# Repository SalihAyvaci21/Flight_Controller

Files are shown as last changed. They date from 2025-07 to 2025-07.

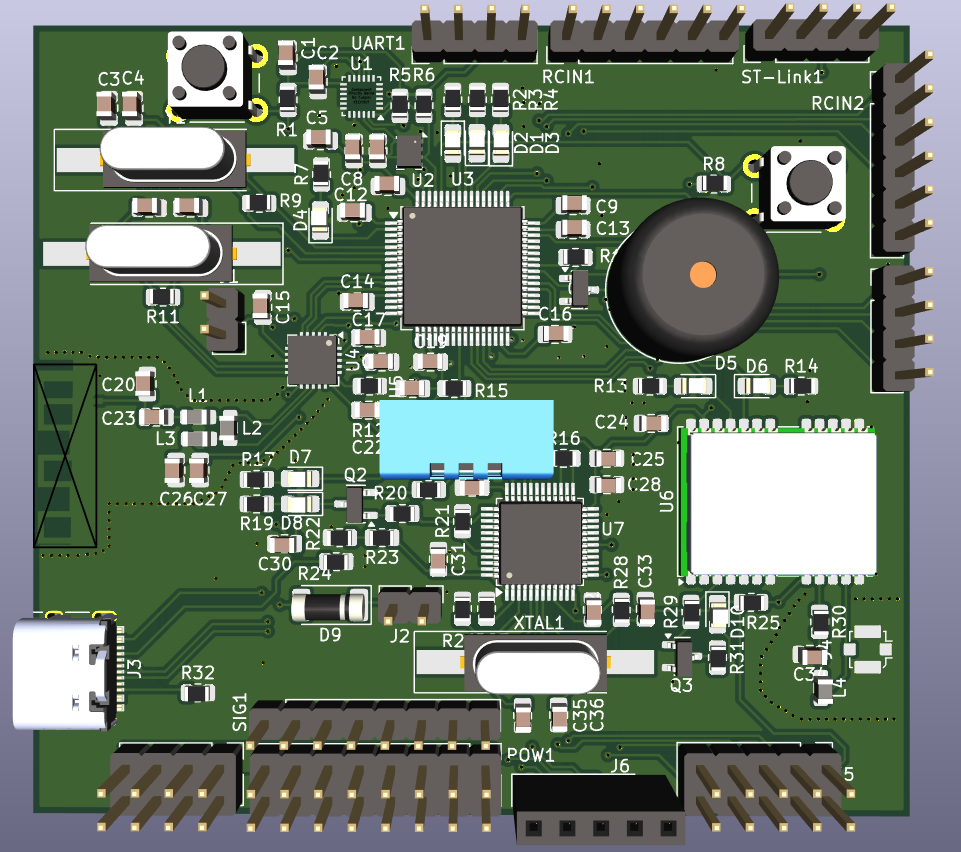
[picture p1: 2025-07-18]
Ucus kartı v312/Ucus kartı v3/Images/3D Images.PNG

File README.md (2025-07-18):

#  STM32F405RGT Flight Controller & Development Board

Bu proje, **STM32F405RGT6 (64-pin)** mikrodenetleyicisi tabanlı bir uçuş kartı ve aynı zamanda **entegre ST-LINK** programlayıcısı ile bir geliştirme kartı olarak kullanılabilecek bir donanım platformudur.  

Kart, uçuş modlarını kontrol etmek için kritik sensörler ve genişletilebilir pin yapısıyla tasarlanmıştır. Hem uçuş kontrolü hem de genel gömülü sistem geliştirme için idealdir.

## ✨ Özellikler

- **MCU**: STM32F405RGT6 (Cortex-M4, 1MB Flash, 192KB SRAM, 64-pin LQFP)
- **ST-LINK v2.1**: Dahili programlayıcı (STM32F103CBT tabanlı)
- **Sensörler**:
  - MPU-9250 (9 Eksen IMU - Gyro, Accelerometer, Magnetometer)
  - BMP180 (Barometrik basınç ve sıcaklık sensörü)
  - DHT11 (Nem ve sıcaklık sensörü)
  - (MPU9250 + BMP180 kombinasyonu Türkiye’de kolay bulunabilir)
- **Kablosuz Haberleşme**:
  - **nRF24L01**: Yer istasyonu ile veri alışverişi
  - **GPS**: Neo-8Q (Pin-to-Pin uyumlu M8N alternatifi)
  - Harici anten çıkışı (değiştirilebilir)
- **GPIO**:
  - 4x LED (Uçuş modları için): `PA0`, `PA1`, `PA2`, `PA3`
  - 2x Güç LED’i (3.3V & 5V)
  - Buzzer: `PA8`
  - PWM Çıkışları: `PA0` - `PA3`
  - Boot & Reset düğmeleri
  - Programlama pinleri: `PA13`, `PA14` (SWD)
  - UART4 (ST-LINK üzerinden): `PC10` (TX), `PC11` (RX)
  - Çoğu GPIO **boşta bırakıldı**, kullanıcı entegrasyonu için hazır

---

## 📡 Kablosuz Özellikler

| Bileşen | Açıklama |
|---|---|
| **nRF24L01** | Yer istasyonu ile haberleşme için |
| **Neo-8Q GPS** | Konumlandırma ve uçuş rotası takibi |
| **Anten Çıkışı**| Harici anten bağlantısı, değiştirilebilir |

---

## 🛠️ Kullanım Senaryoları

- 🚁 Drone/UAV uçuş kontrolü
- 🧑‍💻 STM32 geliştirme platformu
- 📡 Kablosuz veri iletimi prototipleri
- 📦 Sensör entegrasyonu için araştırma & eğitim projeleri

---

## 🔌 Pinout & Peripherals

| Fonksiyon | Pinler |
|---|---|
| Uçuş Modu LED’leri | PA0, PA1, PA2, PA3  |
| Güç LED’leri | 3.3V, 5V |
| Buzzer | PA8 |
| Boot & Reset Butonları| GPIO kontrollü |
| PWM Çıkışları | PA0 - PA3 |
| SWD Programlama | PA13, PA14 |
| UART4 (ST-LINK) | PC10 (TX), PC11 (RX)|
| GPS | Harici bağlantı |
| nRF24L01 | SPI bağlantısı |

---

## ⚙️ Programlama & Debug

- **ST-LINK Dahili**
  - STM32F103CBT tabanlı entegre ST-LINK
  - SWD pinleri dışarı alınmıştır (`PA13`, `PA14`)
  - STM32CubeProgrammer veya OpenOCD ile uyumlu
- **UART Debugging**
  - UART4 üzerinden ST-LINK’e bağlantı

---

## 📦 Entegrasyon & Genişletilebilirlik

- Tüm kritik uçuş sensörleri **entegre edilmiştir**  
- Çoğu GPIO boşta bırakılmıştır – ek donanımlar ve özel modüller için kullanılabilir
- Geliştiriciler kendi devrelerini veya sensörlerini kolayca entegre edebilir

---

## 🚀 Başlarken

1. USB üzerinden bilgisayara bağlanın (ST-LINK otomatik tanınır)
2. STM32CubeProgrammer ile firmware yükleyin
3. Harici sensörleri ve modülleri GPIO’lara bağlayın
4. UART4 ile seri haberleşmeyi başlatın

---

## 📃 Lisans

Bu proje tamamen açık kaynaklıdır. İsteyen herkes geliştirme ve entegrasyon yapabilir.

---

## 📝 Notlar
- MPU9250 ve BMP180 Türkiye’de kolay bulunabilir ve birlikte modül olarak satılmaktadır.
- GPS için Neo-8Q kullanılmıştır; Pin-to-Pin uyumlu M8N de kullanılabilir.

---

STM32F405RGT Flight Controller & Development Board
This project is a hardware platform based on the STM32F405RGT6 (64-pin) microcontroller, designed as both a flight controller and a development board with an integrated ST-LINK programmer.

The board is equipped with critical sensors for flight modes and an extendable pin structure, making it ideal for both flight control and general embedded system development.

✨ Features
MCU: STM32F405RGT6 (Cortex-M4, 1MB Flash, 192KB SRAM, 64-pin LQFP)

ST-LINK v2.1: Built-in programmer (based on STM32F103CBT)

Sensors:

MPU-9250 (9-axis IMU - Gyroscope, Accelerometer, Magnetometer)

BMP180 (Barometric pressure and temperature sensor)

DHT11 (Humidity and temperature sensor)

(MPU9250 + BMP180 combo is widely available)

Wireless Communication:

nRF24L01: For data exchange with ground station

GPS: Neo-8Q (Pin-compatible with M8N alternative)

External antenna connector (replaceable)

GPIO:

4x LEDs (for flight modes): PA0, PA1, PA2, PA3

2x Power LEDs (3.3V & 5V)

Buzzer: PA8

PWM Outputs: PA0 - PA3

Boot & Reset buttons

Programming pins: PA13, PA14 (SWD)

UART4 (via ST-LINK): PC10 (TX), PC11 (RX)

Most GPIOs are left free for user integration

📡 Wireless Features
Component	Description
nRF24L01	Communication with ground station
Neo-8Q GPS	Positioning and flight route tracking
Antenna Out	External antenna connector, replaceable

🛠️ Use Cases
🚁 Drone/UAV flight control

🧑‍💻 STM32 development platform

📡 Wireless data transmission prototypes

📦 Research & educational projects for sensor integration

🔌 Pinout & Peripherals
Function	Pins
Flight Mode LEDs	PA0, PA1, PA2, PA3
Power LEDs	3.3V, 5V
Buzzer	PA8
Boot & Reset Buttons	GPIO controlled
PWM Outputs	PA0 - PA3
SWD Programming	PA13, PA14
UART4 (ST-LINK)	PC10 (TX), PC11 (RX)
GPS	External connection
nRF24L01	SPI interface

⚙️ Programming & Debug
Built-in ST-LINK

Based on STM32F103CBT

SWD pins exposed (PA13, PA14)

Compatible with STM32CubeProgrammer and OpenOCD

UART Debugging

Connected via UART4 to ST-LINK

📦 Integration & Expandability
All critical flight sensors are integrated

Most GPIOs are left free – ready for additional hardware or custom modules

Developers can easily integrate their own circuits or sensors

🚀 Getting Started
Connect to PC via USB (ST-LINK auto-detected)

Flash firmware using STM32CubeProgrammer

Connect external sensors and modules to GPIOs

Start serial communication via UART4

📃 License
This project is fully open-source. Anyone is free to develop and integrate.

📝 Notes
MPU9250 and BMP180 are widely available and often sold as combined modules.

Neo-8Q GPS is used; Pin-compatible M8N can also be used.

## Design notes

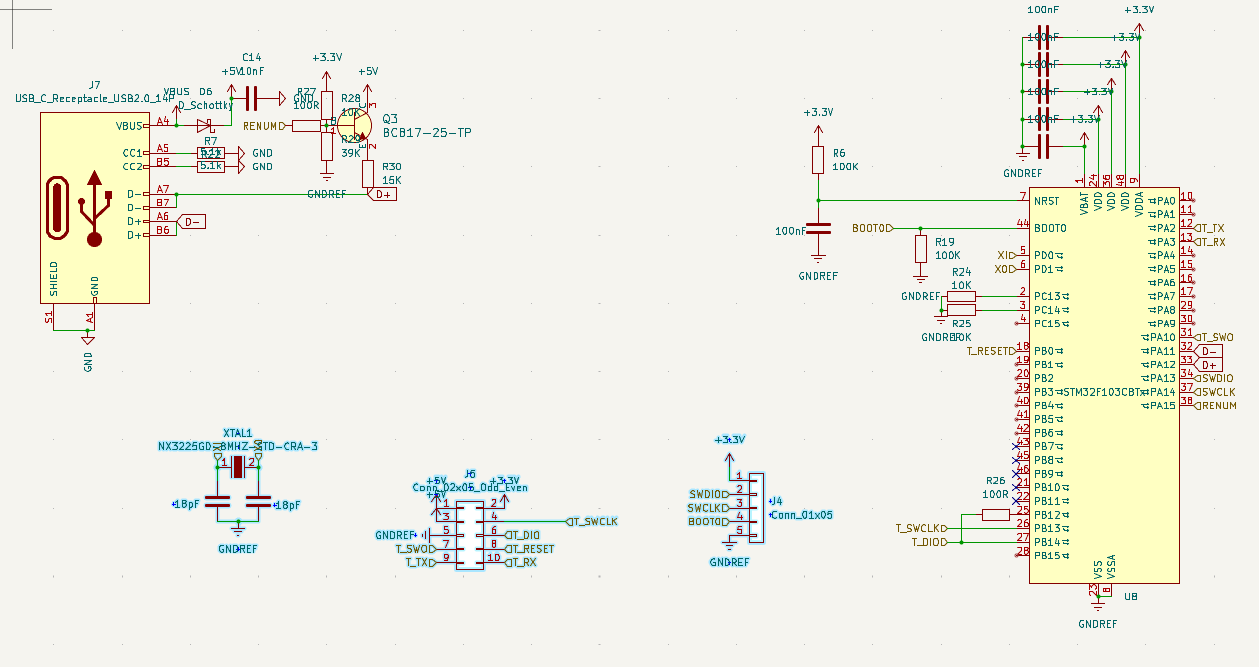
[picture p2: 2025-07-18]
Ucus kartı v312/Ucus kartı v3/Images/Schematic ST-Link.PNG

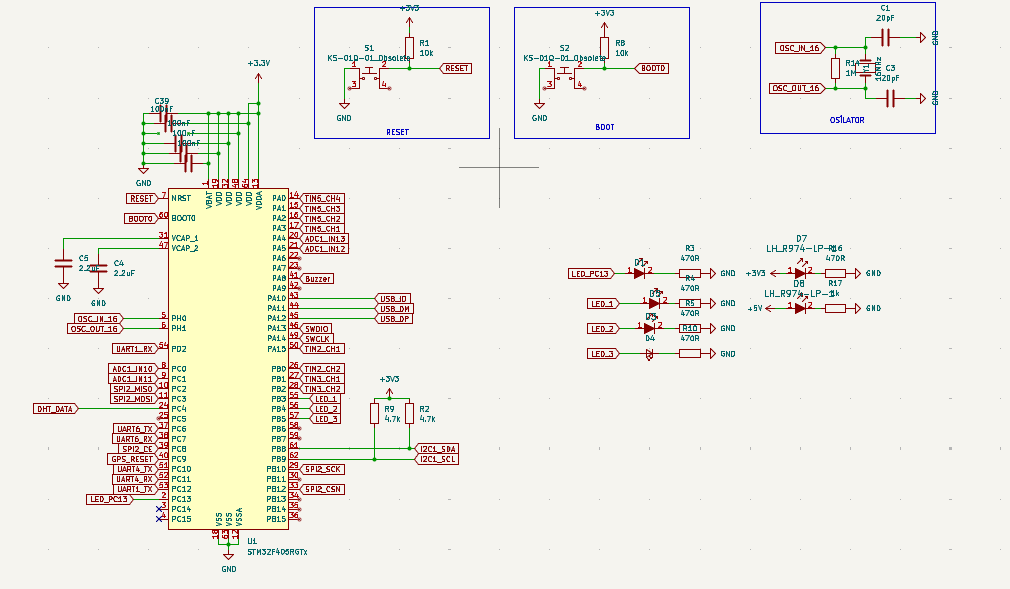
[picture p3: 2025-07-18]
Ucus kartı v312/Ucus kartı v3/Images/Schematic Microcontroller.PNG

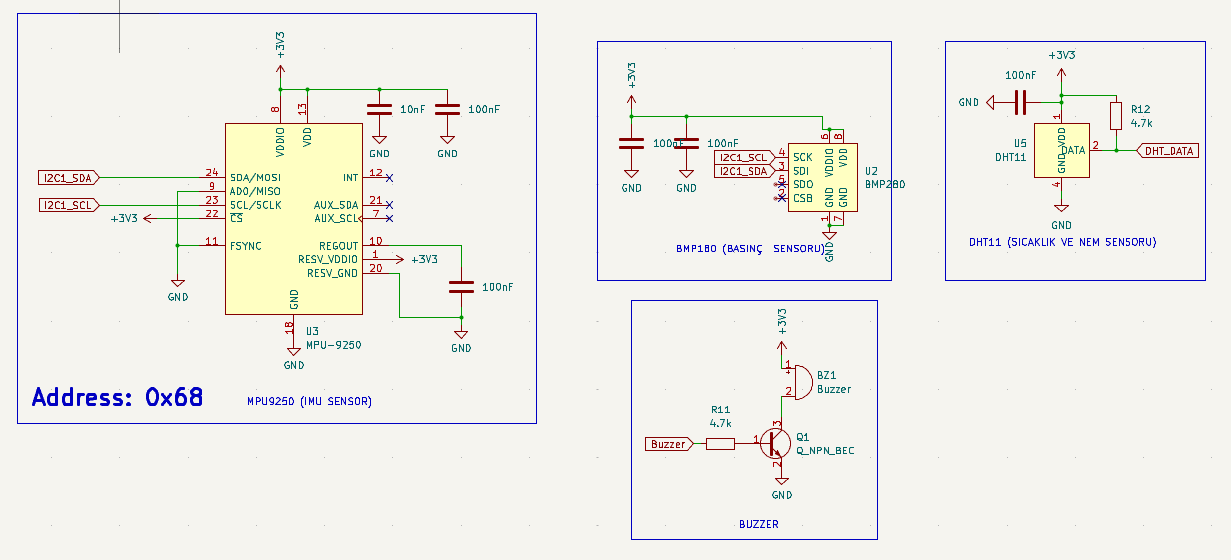
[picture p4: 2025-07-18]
Ucus kartı v312/Ucus kartı v3/Images/Schematic Sensor.PNG

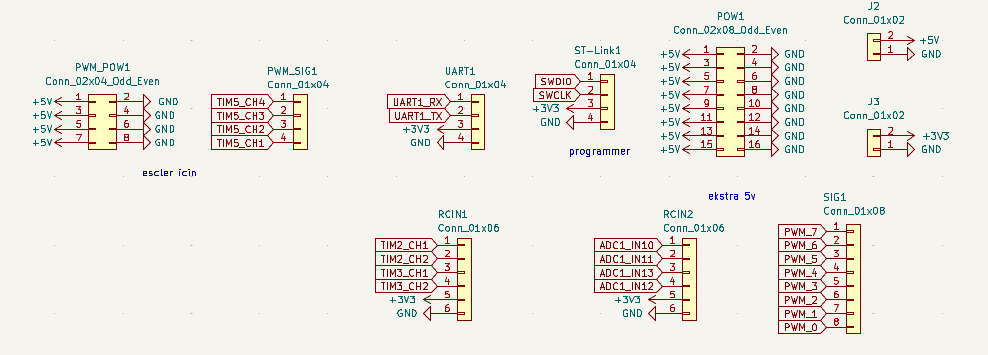
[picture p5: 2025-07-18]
Ucus kartı v312/Ucus kartı v3/Images/Schematic connectors.PNG

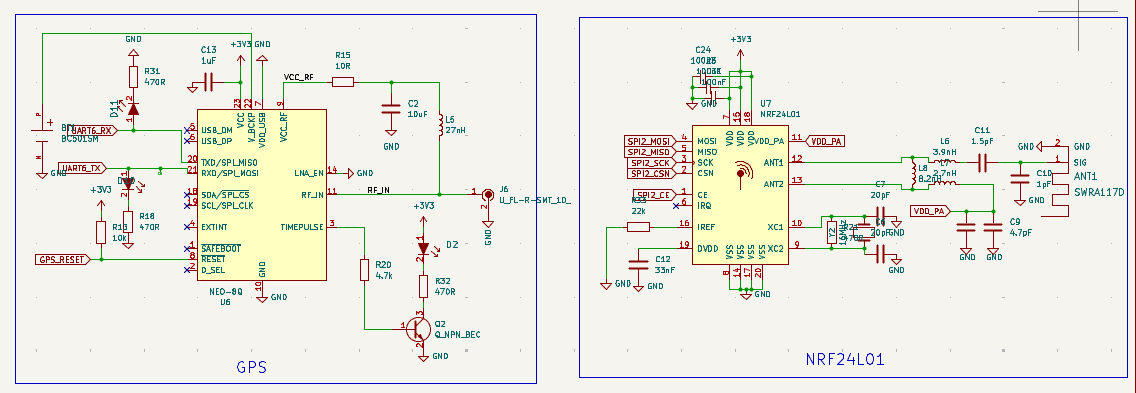
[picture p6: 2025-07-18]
Ucus kartı v312/Ucus kartı v3/Images/Schematic Wireless.PNG

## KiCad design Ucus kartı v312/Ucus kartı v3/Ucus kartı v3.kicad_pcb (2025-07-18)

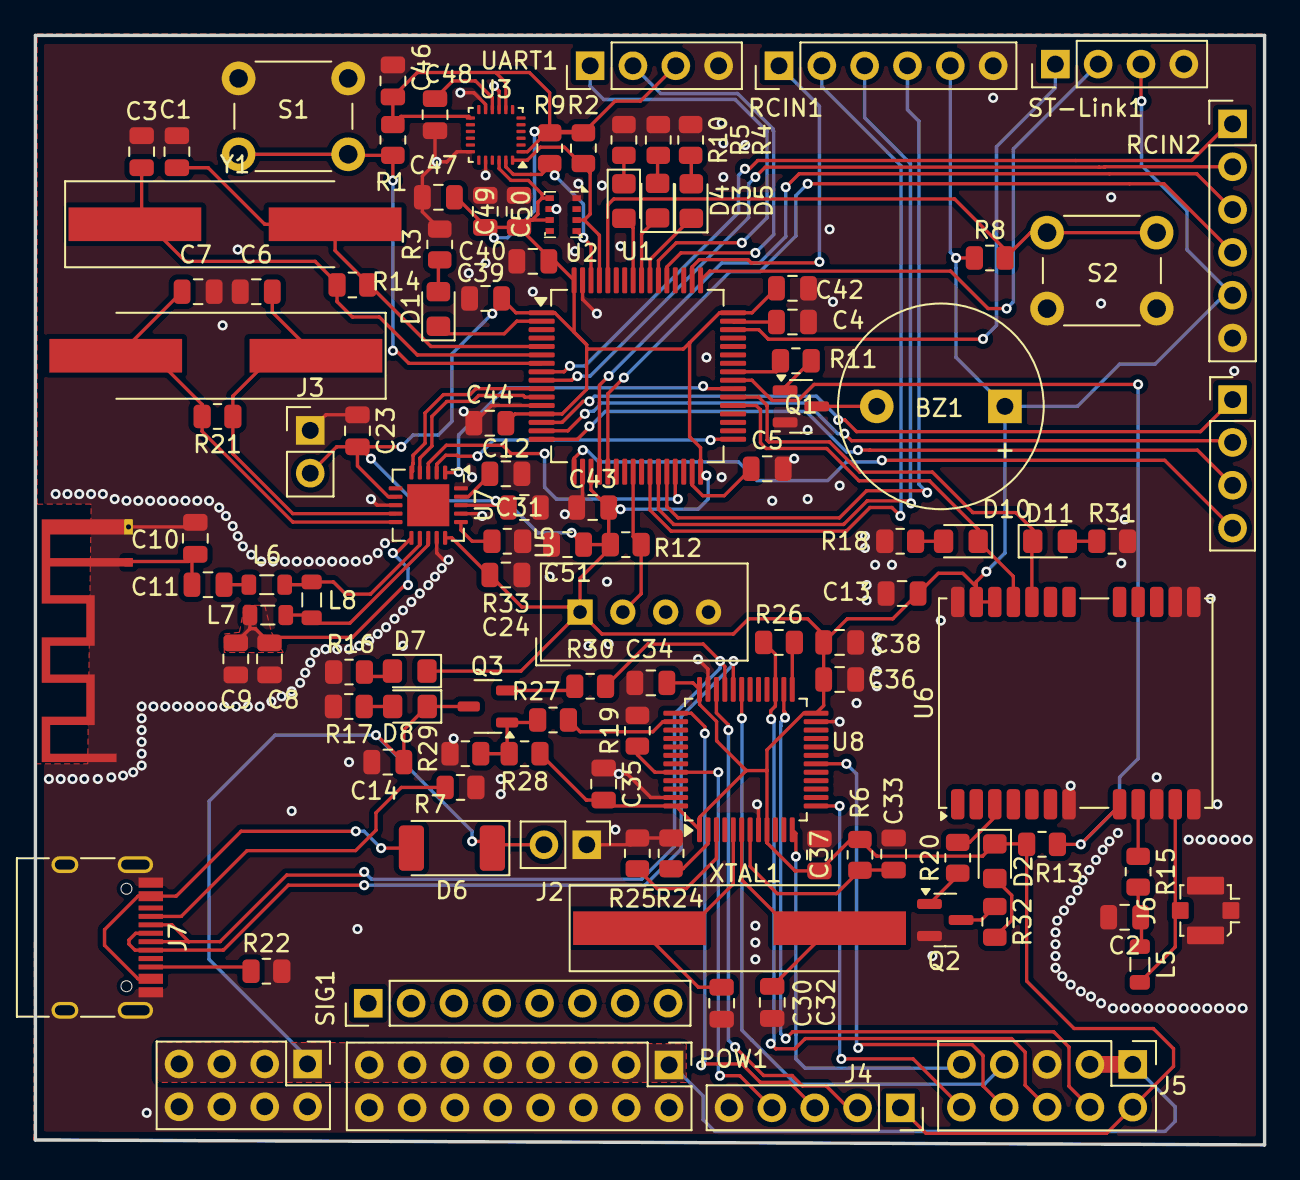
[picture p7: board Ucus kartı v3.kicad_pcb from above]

Board: 2 copper layers, 72.9 x 65.8 mm, 113 parts (0 on the bottom side), 91 nets.

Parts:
ANT1: SWRA117D; Texas_SWRA117D_2.4GHz_Left
BZ1: Buzzer; Buzzer_12x9.5RM7.6
C1, C3, C6, C7: 20pF; C_0805_2012Metric
C2: 10uF; C_0805_2012Metric
C4, C5: 2.2uF; C_0805_2012Metric
C8: 2.2nF; C_0805_2012Metric
C9: 4.7pF; C_0805_2012Metric
C10: 1pF; C_0805_2012Metric
C11: 1.5pF; C_0805_2012Metric
C12: 33nF; C_0805_2012Metric
C13: 1uF; C_0805_2012Metric
C14, C46: 10nF; C_0805_2012Metric
C23, C24, C31, C33, C34, C35, C36, C37, C38, C39, C40, C42, C43, C44, C47, C48, C49, C50, C51: 100nF; C_0805_2012Metric
C30, C32: 18pF; C_0805_2012Metric
D1, D7, D8: LH_R974-LP-1; LED_0805_2012Metric_Pad1.15x1.40mm_HandSolder
D2: G/LTST-C171KGKT; LED_0805_2012Metric_Pad1.15x1.40mm_HandSolder
D3, D5: B/LTST-C170TBKT; LED_0805_2012Metric_Pad1.15x1.40mm_HandSolder
D4, D10, D11: R/LH_R974-LP-1; LED_0805_2012Metric_Pad1.15x1.40mm_HandSolder
D6: D_Schottky; D_MELF
J2, J3: Conn_01x02; PinHeader_1x02_P2.54mm_Vertical
J4: Conn_01x05; PinSocket_1x05_P2.54mm_Vertical
J5: Conn_02x05_Odd_Even; PinHeader_2x05_P2.54mm_Vertical
J6: U_FL-R-SMT_10_; U.FL_Molex_MCRF_73412-0110_Vertical
J7: USB_C_Receptacle_USB2.0_14P; USB_C_Receptacle_HRO_TYPE-C-31-M-12
L5: 27nH; L_0805_2012Metric
L6: 3.9nH; L_0805_2012Metric
L7: 2.7nH; L_0805_2012Metric
L8: 8.2nH; L_0805_2012Metric
POW1: Conn_02x08_Odd_Even; PinHeader_2x08_P2.54mm_Vertical
PWM_POW1: Conn_02x04_Odd_Even; PinHeader_2x04_P2.54mm_Vertical
PWM_SIG1: Conn_01x04; PinHeader_1x04_P2.54mm_Vertical
Q1, Q2: Q_NPN_BEC; SOT-23
Q3: BC817-25-TP; SOT-23-3
R1, R8, R13: 10k; R_0805_2012Metric
R2, R9, R11, R12, R20: 4.7k; R_0805_2012Metric
R3, R4, R5, R10, R16, R18, R21, R31, R32: 470R; R_0805_2012Metric
R6, R19: 100K; R_0805_2012Metric
R7, R22: 5.1k; R_0805_2012Metric
R14: 1M; R_0805_2012Metric
R15: 10R; R_0805_2012Metric
R17: 1k; R_0805_2012Metric
R24, R25, R28: 10K; R_0805_2012Metric
R26, R27: 100R; R_0805_2012Metric
R29: 39K; R_0805_2012Metric
R30: 15K; R_0805_2012Metric
R33: 22k; R_0805_2012Metric
RCIN1, RCIN2: Conn_01x06; PinHeader_1x06_P2.54mm_Vertical
S1, S2: KS-01Q-01_Obsolete; SW_PUSH_6mm_H4.3mm
SIG1: Conn_01x08; PinHeader_1x08_P2.54mm_Vertical
ST-Link1: Conn_01x04; PinHeader_1x04_P2.54mm_Vertical
U1: STM32F405RGTx; LQFP-64_10x10mm_P0.5mm
U2: BMP280; Bosch_LGA-8_2x2.5mm_P0.65mm_ClockwisePinNumbering
U3: MPU-9250; InvenSense_QFN-24_3x3mm_P0.4mm
U5: DHT11; Aosong_DHT11_5.5x12.0_P2.54mm
U6: NEO-8Q; ublox_NEO
U7: NRF24L01; QFN-20-1EP_4x4mm_P0.5mm_EP2.5x2.5mm
U8: STM32F103CBTx; LQFP-48_7x7mm_P0.5mm
UART1: Conn_01x04; PinHeader_1x04_P2.54mm_Vertical
XTAL1: NX3225GD-8MHZ-STD-CRA-3; Crystal_SMD_HC49-SD_HandSoldering
Y1, Y2: 16MHz; Crystal_SMD_HC49-SD_HandSoldering

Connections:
+3.3V: BZ1.1 (-), C13.2, C23.2, C24.2, C31.2, C34.2, C35.2, C36.2, C37.2, C38.2, C39.2, C40.2, C42.2, C43.2, C44.2, C46.2, C47.2, C49.2, C50.2, C51.1, D2.1, D7.1, J3.2, J4.1, J5.2, R1.1, R2.1, R6.1, R8.1, R9.1, R12.2, R13.2, R28.1, RCIN1.5, RCIN2.5, ST-Link1.3, U1.1 (VBAT), U1.13 (VDDA), U1.19 (VDD), U1.32 (VDD), U1.48 (VDD), U1.64 (VDD), U2.6 (VDDIO), U2.8 (VDD), U3.1 (RESV_VDDIO), U3.8 (VDDIO), U3.13 (VDD), U3.22 (~CS), U5.1 (VDD), U6.22 (V_BCKP), U6.23 (VCC), U7.7 (VDD), U7.15 (VDD), U7.18 (VDD), U8.1 (VBAT), U8.9 (VDDA), U8.24 (VDD), U8.36 (VDD), U8.48 (VDD), UART1.3
+5V: C14.1, D6.1 (K), D8.1, J2.2, J5.1, J5.3, POW1.1, POW1.3, POW1.5, POW1.7, POW1.9, POW1.11, POW1.13, POW1.15, PWM_POW1.1, PWM_POW1.3, PWM_POW1.5, PWM_POW1.7, Q3.3 (C)
/KABLOSUZ HABERLEŞME/RF_IN: J6.1, L5.2, U6.11 (RF_IN)
/KABLOSUZ HABERLEŞME/VCC_RF: R15.1, U6.9 (VCC_RF)
/stlink/BOOT0: J4.4, R19.1, U8.44 (BOOT0)
/stlink/RENUM: R27.2, U8.38 (PA15)
/stlink/SWCLK: J4.3, U8.37 (PA14)
/stlink/SWDIO: J4.2, U8.34 (PA13)
/stlink/T_DIO: J5.6, R26.1, U8.27 (PB14)
/stlink/T_RESET: J5.8, U8.18 (PB0)
/stlink/T_RX: J5.10, U8.13 (PA3)
/stlink/T_SWCLK: J5.4, U8.26 (PB13)
/stlink/T_SWO: J5.7, U8.31 (PA10)
/stlink/T_TX: J5.9, U8.12 (PA2)
/stlink/X0: C32.2, U8.6 (PD1), XTAL1.2
/stlink/XI: C30.2, U8.5 (PD0), XTAL1.1
ADC1_IN10: RCIN2.1, U1.8 (PC0)
ADC1_IN11: RCIN2.2, U1.9 (PC1)
ADC1_IN12: RCIN2.4, U1.21 (PA5)
ADC1_IN13: RCIN2.3, U1.20 (PA4)
BOOT0: R8.2, S2.2, U1.60 (BOOT0)
Buzzer: R11.1, U1.41 (PA8)
D+: J7.A7 (D-), J7.B7 (D-), R30.2, U8.33 (PA12)
D-: J7.A6 (D+), J7.B6 (D+), U8.32 (PA11)
DHT_DATA: R12.1, U1.24 (PC4), U5.2 (DATA)
GND: ANT1.2 (GND), C1.2, C2.2, C3.2, C4.2, C5.2, C6.2, C7.2, C8.1, C9.1, C10.1, C12.2, C13.1, C14.2, C23.1, C24.1, C30.1, C31.1, C32.1, C33.1, C34.1, C35.1, C36.1, C37.1, C38.1, C39.1, C40.1, C42.1, C43.1, C44.1, C46.1, C47.1, C48.1, C49.1, C50.1, C51.2, J2.1, J3.1, J4.5, J5.5, J6.2, J7.A1 (GND), J7.A12 (GND), J7.B1 (GND), J7.B12 (GND), J7.S1 (SHIELD), POW1.2, POW1.4, POW1.6, POW1.8, POW1.10, POW1.12, POW1.14, POW1.16, PWM_POW1.2, PWM_POW1.4, PWM_POW1.6, PWM_POW1.8, Q1.2 (E), Q2.2 (E), R3.2, R4.2, R5.2, R7.2, R10.2, R16.2, R17.2, R18.1, R19.2, R22.2, R24.1, R25.1, R29.2, R31.2, R33.2, RCIN1.6, RCIN2.6, S1.1, S2.1, ST-Link1.4, U1.12 (VSSA), U1.18 (VSS), U1.63 (VSS), U2.1 (GND), U2.7 (GND), U3.9 (AD0/MISO), U3.11 (FSYNC), U3.18 (GND), U3.20 (RESV_GND), U5.4 (GND), U6.7 (VDD_USB), U6.10 (GND), U6.12 (GND), U6.13 (GND), U6.14 (LNA_EN), U6.24 (GND), U7.8 (VSS), U7.14 (VSS), U7.17 (VSS), U7.20 (VSS), U8.8 (VSSA), U8.23 (VSS), U8.35 (VSS), U8.47 (VSS), UART1.4
GPS_RESET: R13.1, U1.40 (PC9), U6.8 (~RESET)
I2C1_SCL: R9.2, U1.62 (PB9), U2.4 (SCK), U3.23 (SCL/SCLK)
I2C1_SDA: R2.2, U1.61 (PB8), U2.3 (SDI), U3.24 (SDA/MOSI)
LED_1: D5.1, U1.55 (PB3)
LED_2: D3.1, U1.56 (PB4)
LED_3: D4.2 (A), U1.57 (PB5)
LED_PC13: D1.1, U1.2 (PC13)
unnamed: ANT1.1 (SIG), C10.2, C11.1
unnamed: BZ1.2 (+), Q1.3 (C)
unnamed: C2.1, L5.1, R15.2
unnamed: C11.2, L6.2
unnamed: D1.2, R3.1
unnamed: D2.2, R32.2
unnamed: D3.2, R5.1
unnamed: D4.1 (K), R10.1
unnamed: D5.2, R4.1
unnamed: D7.2, R16.1
unnamed: D8.2, R17.1
unnamed: D10.2, R18.2
unnamed: D11.2, R31.1
unnamed: J7.A5 (CC1), R7.1
unnamed: J7.B5 (CC2), R22.1
unnamed: Q1.1 (B), R11.2
unnamed: Q2.1 (B), R20.1
unnamed: Q2.3 (C), R32.1
unnamed: Q3.1 (B), R27.1, R28.2, R29.1
unnamed: Q3.2 (E), R30.1
unnamed: C5.1, U1.31 (VCAP_1)
unnamed: C4.1, U1.47 (VCAP_2)
unnamed: C48.2, U3.10 (REGOUT)
unnamed: R20.2, U6.3 (TIMEPULSE)
unnamed: L6.1, L8.1, U7.12 (ANT1)
unnamed: L7.1, L8.2, U7.13 (ANT2)
unnamed: C12.1, U7.19 (DVDD)
unnamed: R33.1, U7.16 (IREF)
unnamed: C7.1, R21.2, U7.10 (XC1), Y2.2
unnamed: C6.1, R21.1, U7.9 (XC2), Y2.1
unnamed: C33.2, R6.2, U8.7 (NRST)
unnamed: R26.2, U8.25 (PB12)
unnamed: R24.2, U8.2 (PC13)
unnamed: R25.2, U8.3 (PC14)
OSC_IN_16: C1.1, R14.1, U1.5 (PH0), Y1.2
OSC_OUT_16: C3.1, R14.2, U1.6 (PH1), Y1.1
RESET: R1.2, S1.2, U1.7 (NRST)
SPI2_CE: U1.39 (PC8), U7.1 (CE)
SPI2_CSN: U1.33 (PB12), U7.2 (CSN)
SPI2_MISO: U1.10 (PC2), U7.5 (MISO)
SPI2_MOSI: U1.11 (PC3), U7.4 (MOSI)
SPI2_SCK: U1.29 (PB10), U7.3 (SCK)
SWCLK: ST-Link1.2, U1.49 (PA14)
SWDIO: ST-Link1.1, U1.46 (PA13)
TIM2_CH1: RCIN1.1, U1.50 (PA15)
TIM2_CH2: RCIN1.2, U1.26 (PB0)
TIM3_CH1: RCIN1.3, U1.27 (PB1)
TIM3_CH2: RCIN1.4, U1.28 (PB2)
TIM5_CH1: PWM_SIG1.4, U1.17 (PA3)
TIM5_CH2: PWM_SIG1.3, U1.16 (PA2)
TIM5_CH3: PWM_SIG1.2, U1.15 (PA1)
TIM5_CH4: PWM_SIG1.1, U1.14 (PA0)
UART1_RX: U1.54 (PD2), UART1.1
UART1_TX: U1.53 (PC12), UART1.2
UART6_RX: D11.1, U1.38 (PC7), U6.20 (TXD/SPI_MISO)
UART6_TX: D10.1, U1.37 (PC6), U6.21 (RXD/SPI_MOSI)
VBUS: D6.2 (A), J7.A4 (VBUS), J7.A9 (VBUS), J7.B4 (VBUS), J7.B9 (VBUS)
VDD_PA: C8.2, C9.2, L7.2, U7.11 (VDD_PA)
